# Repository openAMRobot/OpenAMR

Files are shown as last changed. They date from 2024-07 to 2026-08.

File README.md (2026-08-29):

# OpenAMRobot

## Turn Domain Expertise into Robotic Skills by Demonstration

### The Programming Language of Robotics is Domain Expertise.

OpenAMRobot is an open-source Physical AI development platform that enables startups, researchers, universities, and domain experts to build, train, validate, and deploy robotic solutions without rebuilding the entire robotics stack.

We believe the future of robotics will not be built by robotics engineers alone.

It will be built by:

- Manufacturing experts
- Logistics specialists
- Healthcare professionals
- Researchers
- Entrepreneurs
- Innovators

People who understand problems and want to automate them.

OpenAMRobot provides the infrastructure that transforms domain expertise into robotic capabilities.

---

# ⚠️ This Repository Has Moved

OpenAMR has evolved into a modular, better organized project.

As part of the **OpenAMRobot v0.0.1** release, the original repository has been split into dedicated repositories for hardware, software, firmware, and documentation.

## 📢 What Happened?

Most of the content previously available in this repository has been:

- ➜ migrated to **openamr-platform-hw**
- ➜ partially migrated to **openamr-platform-fw**
- ➜ reorganized into a modular repository structure
- ➜ updated with improved documentation and architecture

The legacy repository is now kept mainly for historical reference.

---
## 📦 New Project Structure

### 🛠️ Hardware
https://github.com/openAMRobot/openamr-platform-hw

Complete mechanical design, CAD, manufacturing files, BOM, electrical documentation, chassis, wiring, and assembly documentation.

### 🤖 Software
https://github.com/openAMRobot/openamr-platform-sw

ROS 2 Jazzy, Nav2, Gazebo Harmonic, SLAM, autonomous navigation, auto-docking, UI, simulation, Docker, and robotics software.

### ⚙️ Firmware
https://github.com/openAMRobot/openamr-platform-fw

micro-ROS firmware, motor control, odometry, IMU integration, PID control, telemetry, safety framework, and embedded software.

---
## 🚀 Watch the Release

OpenAMRobot v0.0.1 Release (https://www.youtube.com/shorts/LCLWUHWGkIY)

▶️ **OpenAMRobot v0.0.1 — First Public Release**

---

## ❤️ Continue the Journey

OpenAMRobot is becoming an open ecosystem for embodied AI, autonomous mobile robots, and mobile manipulation.

If you're looking for the latest development, please start here:

👉 https://github.com/openAMRobot

⭐ Star the project if you'd like to support open robotics.

---

## Why OpenAMRobot?

Building a modern Physical AI system requires expertise across:

- Robotics
- AI
- Perception
- Teleoperation
- Data collection
- Simulation
- Training infrastructure
- Deployment

Most teams spend months assembling infrastructure before they can validate a single robotic application.

OpenAMRobot reduces this complexity by providing an integrated development platform for:

- Mobile manipulation
- Teleoperation
- Data collection
- Imitation learning
- Embodied AI research
- Human-in-the-loop training
- Robot skill development
- Real-world deployment

**The fastest path from business problem to robotic solution.**

---

## Robotics 3.0

### Software evolution

**Software 1.0**  
Write code

**Software 2.0**  
Train models

**Software 3.0**  
Describe outcomes

### Robotics evolution

**Robotics 1.0**  
Program robots

**Robotics 2.0**  
Train robots

**Robotics 3.0**  
Teach robots by demonstration

OpenAMRobot is building the platform for Robotics 3.0.

---

## How it works

Domain Expert  
↓  
Demonstrates Task  
↓  
OpenAMRobot Collects Data  
↓  
AI Learns Skill  
↓  
Robot Executes Task

OpenAMRobot connects hardware, software, AI, and deployment into a single workflow.

---

## What OpenAMRobot provides

### Reference hardware

- Autonomous mobile robot platform
- Dual-arm mobile manipulation
- Adjustable lift systems
- Modular sensor architecture
- Open hardware designs

### Software infrastructure

- ROS 2 ecosystem
- Navigation and autodocking
- Teleoperation interfaces
- Simulation environments
- Embedded firmware

### Physical AI infrastructure

- Demonstration data collection
- ROS bag recording
- Dataset generation
- Imitation learning pipelines
- Foundation model integration
- Policy training workflows
- Deployment infrastructure

---

## Who is OpenAMRobot for?

### Today

- Robotics startups
- Universities
- Research laboratories
- Corporate innovation teams
- Venture builders

### Tomorrow

- Manufacturing
- Logistics
- Healthcare
- Agriculture
- Service robotics

Our users build robots.

Their users deploy robots.

---

## Why OpenAMRobot matters

Physical AI is creating a new generation of robots that learn from demonstration, adapt to new tasks, and solve real-world problems.

Yet building a trainable robot still requires expertise across hardware, software, AI, teleoperation, data collection, training pipelines, simulation, deployment, and hardware integration.

OpenAMRobot reduces this complexity by providing an integrated platform that enables anyone with domain expertise to create robotic solutions.

The real value is not the robot itself.

The real value is how efficiently a robotic system can solve a business problem.

---

## Our vision

The next generation of creators will not just build software.

They will build robots.

OpenAMRobot enables anyone with domain expertise to create robotic solutions without becoming a robotics engineer.

**The Programming Language of Robotics is Domain Expertise.**

---

## 💜 Support OpenAMRobot

Support open-source robotics, ROS 2 development, AI robotics education, and dual-arm mobile robot research.

### ⚡ Back the build — one-time, no strings

| Tier | What it says about you | Link |
|---|---|---|
| ⚡ **First Mover - €5** | You got here first, and you didn't overthink it. Your name goes on the backers wall - permanently - as one of the people who moved before it was obvious. Five euros, one good instinct. | <a href="https://buy.stripe.com/eVqcN5b99eeAaSd7WPgUM06" target="_blank" rel="noopener noreferrer">💳&nbsp;Back&nbsp;it&nbsp;→</a> |
| 🎯 **Sharpshooter - €25** | You spotted it early and called it. Name on the wall + a shareable "OpenAMRobot Backer" badge - proof you saw it coming while everyone else was still scrolling. | <a href="https://buy.stripe.com/4gMdR9ell1rO2lH90TgUM07" target="_blank" rel="noopener noreferrer">💳&nbsp;Back&nbsp;it&nbsp;→</a> |
| 🕶️ **Insider - €50** | You want in behind the curtain. Everything above + the backer-only build log and early files - every breakthrough, every faceplant, unfiltered. You see it before the internet does. | <a href="https://buy.stripe.com/eVq14nfpp4E0gcx2CvgUM08" target="_blank" rel="noopener noreferrer">💳&nbsp;Back&nbsp;it&nbsp;→</a> |
| 🔩 **Immortal - €100** | Your name goes on the actual robot. Physically. Forever. A machine will roll around carrying your name long after any of us remember why - and you'll have the photo to prove you were there. | <a href="https://buy.stripe.com/00w00jdhhb2o4tPfphgUM09" target="_blank" rel="noopener noreferrer">💳&nbsp;Back&nbsp;it&nbsp;→</a> |
| 🏆 **Founding Backer - €250** | Not a supporter - a co-author. Everything above + a personal thank-you in a build video. When this becomes something, you were one of the people who decided it would. | <a href="https://buy.stripe.com/28EeVdcdddawaSdeldgUM0a" target="_blank" rel="noopener noreferrer">💳&nbsp;Back&nbsp;it&nbsp;→</a> |

### 🔁 Monthly subscriptions — build it with us, every month

| Tier | What you get | Link |
|---|---|---|
| 😇 **Benefactor - €5/mo** | This month, officially not wasted. €5 to help build an open robot for everyone - cheaper than the coffee you'll forget you bought. Your name goes on the wall. History will remember you - well, me for sure. 🤖 | <a href="https://buy.stripe.com/9B6cN5dhh9Yk7G1cd5gUM05" target="_blank" rel="noopener noreferrer">💳&nbsp;Subscribe&nbsp;→</a> |
| ❤️ **Community - €19/mo** | You're in. Community access, project & roadmap updates, basic documentation, and community Q&A. (Private consultation not included.) | <a href="https://buy.stripe.com/6oUcN55OPc6s3pL4KDgUM00" target="_blank" rel="noopener noreferrer">💳&nbsp;Subscribe&nbsp;→</a> |
| 🔧 **Builder - €79/mo** | For the ones who actually build. Everything in Community + builder docs, monthly group Q&A, selected tutorials, early design updates, and discounts on digital packs. (Private consultation not included.) | <a href="https://buy.stripe.com/14A28r0uvdaw9O9eldgUM01" target="_blank" rel="noopener noreferrer">💳&nbsp;Subscribe&nbsp;→</a> |
| 🚀 **Pro Support - €299/mo** | Expert support for advanced builders, early founders, and small labs. Includes 1 private consulting call per month and up to 3 hours/month of technical guidance. | <a href="https://buy.stripe.com/dRm4gz4KLdaw6BX4KDgUM02" target="_blank" rel="noopener noreferrer">💳&nbsp;Subscribe&nbsp;→</a> |
| 🏢 **Startup Support - €750/mo** | For robotics startups and teams heading toward a prototype. Includes 2 private consulting calls per month, roadmap support, GitHub/documentation review, supplier review, and up to 6 hours/month. | <a href="https://buy.stripe.com/7sY8wPfpp8Ugf8t90TgUM03" target="_blank" rel="noopener noreferrer">💳&nbsp;Subscribe&nbsp;→</a> |
| 🔬 **Lab Support - €1,500/mo** | For universities, corporate labs, and training centers. Includes 4 private sessions per month, lab implementation support, architecture reviews, training-roadmap support, and up to 10 hours/month. | <a href="https://buy.stripe.com/eVq14ndhh2vSaSda4XgUM04" target="_blank" rel="noopener noreferrer">💳&nbsp;Subscribe&nbsp;→</a> |

**❤️ GitHub Sponsors:** <a href="https://github.com/sponsors/openAMRobot" target="_blank" rel="noopener noreferrer"> 🐙 &nbsp;github.com/sponsors/openAMRobot&nbsp;→</a>

*Every contribution — €5 or €1,500 — literally builds this robot. No billion-dollar lab required. **You're not donating. You're building it.** 🤖*

> [!IMPORTANT]
> ## OpenAMRobot Ecosystem
>
> OpenAMRobot is transitioning from a monolithic repository structure into a modular robotics ecosystem.
>
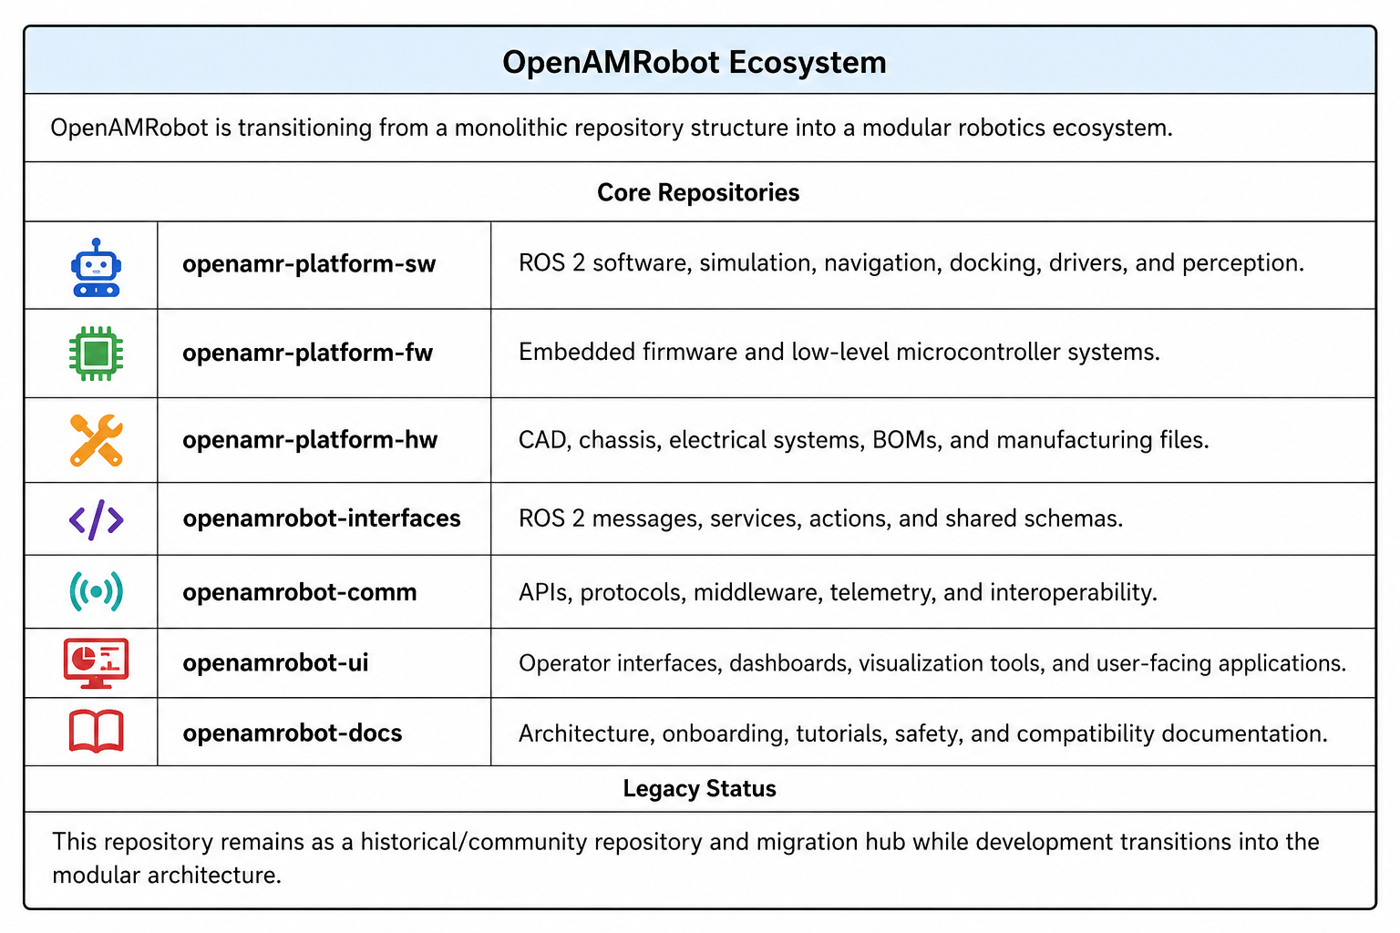
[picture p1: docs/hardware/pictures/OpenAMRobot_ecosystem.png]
OpenAMRobot Ecosystem
> 
>
> ### Core Repositories
>
> | Repository | Purpose |
> |---|---|
> | `openamr-platform-sw` | ROS 2 software, simulation, navigation, docking, drivers, perception, and robot bringup |
> | `openamr-platform-fw` | Embedded firmware, low-level microcontroller systems, motor interfaces, and hardware communication |
> | `openamr-platform-hw` | CAD, chassis, electrical systems, BOMs, manufacturing files, and mechatronics |
> | `openamrobot-interfaces` | ROS 2 messages, services, actions, shared schemas, and interface contracts |
> | `openamrobot-comm` | APIs, middleware, telemetry, transport protocols, interoperability, and fleet communication |
> | `openamrobot-ui` | Operator interfaces, dashboards, visualization tools, and user-facing applications |
> | `openamrobot-docs` | Architecture, onboarding, tutorials, safety, compatibility matrices, and contributor documentation |
>
> ### Future Expansion
>
> Planned future ecosystem areas include:
>
> - humanoid and dual-arm robotics
> - fleet management
> - cloud robotics
> - remote operation
> - AI-assisted autonomy
> - industrial integrations
> - educational platforms
>
> ### Legacy Status
>
> This repository remains as a historical/community repository and migration hub while development transitions into the modular architecture.

## Introduction

SMEs across multiple industries can significantly enhance their operations through the adoption of Collaborative Dual-Arm Autonomous Mobile Robots. 
In warehouses and distribution centers, such robots streamline goods movement and order fulfillment by combining autonomous navigation with dexterous dual-arm manipulation, enabling advanced G2P workflows and reducing manual handling. 
In manufacturing environments, they improve production efficiency by autonomously transporting materials between workstations and performing basic assembly or handling tasks. 
For last-mile logistics, including courier, express, parcel (CEP), and grocery delivery, dual-arm AMRs further boost operational efficiency by automating repetitive loading, sorting, and delivery operations.

Our project empowers you to build your own AMR using open-source designs and accessible manufacturing methods. This guide provides detailed drawings, 3D models, Bill of Materials (BOM), hardware architecture, navigation software, and user interface packages. Utilize straightforward manufacturing technologies to learn and integrate advanced automation seamlessly into your business operations.

## Key features

- **Navigation**: LIDAR/SLAM
- **Drive type**: Differential drive
- **Weight**: ~60 kg
- **Camera view**: 120 degrees
- **Speed**: 1500-2000 mm/s (unloaded), 1200-1500 mm/s (loaded)
- **Positioning accuracy**: ±20 mm
- **Dimensions**: 600x800 mm
- **Battery**: 24/48 V, 48-56 Ah, 8 hours life
- **Communication**: Wi-Fi (2.4/5 GHz)
- **Load capacity**: up to 150 kg
- **Operating temperature**: -10°C to +50°C
- **Charging**: Contact/wireless

## Design and manufacturing

Our design is optimized for manufacturability, requiring only basic technologies such as laser cutting, bending, turning (optional), and 3D printing (optional). Using mostly 2mm thick metal sheets, the design is robust yet simple to produce, allowing one person to build the robot in just one day if every part is ready.

Here is how the chassis design looks like:

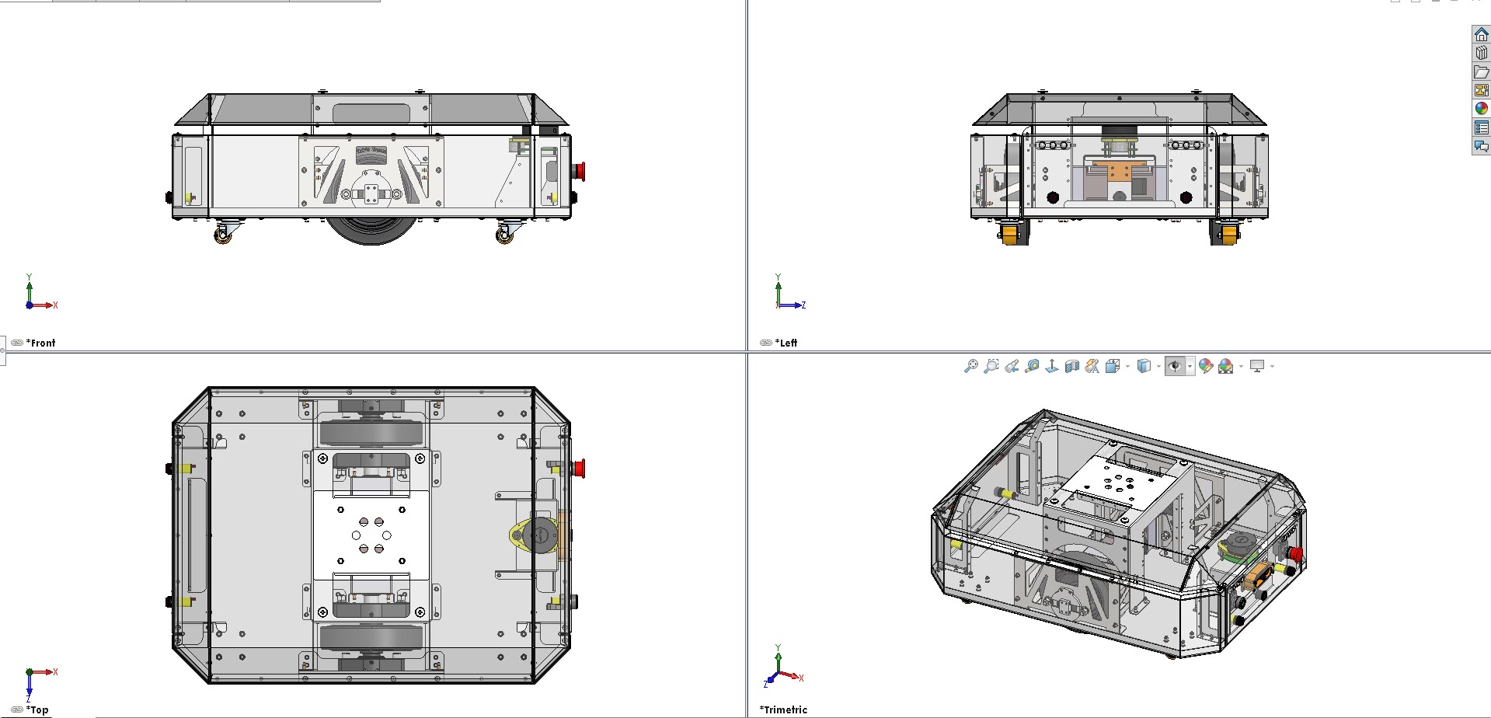
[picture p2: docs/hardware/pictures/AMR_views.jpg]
Mobile Robot General View


### Mechanical design and assembly

1. **Downloadable resources**:
    - Production drawings, 3D models, STEP, and DXF files
    - Specification sheet, including all parts and assemblies, sensors, and fasteners
2. **Fabrication process**:
    - Discuss the drawings with a contractor for cutting and bending metal.
    - Assemble the chassis following the provided sequence.
3. **Assembly steps**:
    - The chassis design and the recommended assembly sequence are illustrated in the provided images.
    - Detailed steps for assembling the drive wheels and other components are included.

### Hardware and software integration

1. **Electronics block diagram**:
    - Main single-board computer (SBC)
    - Safety sensors (US, IR, bumper), RPI camera, and LiDAR
    - Controller Teensy board and firmware
    - BLDC motors, drivers, and encoders
    - Batteries, BMS, and wireless charger
    - On/Off switch and Emergency button

2. **Main components**:
    - **Raspberry Pi 5**: For main computing tasks.
    - **LIDAR**: For mapping and navigation.
    - **Sensors**: For obstacle detection and safety.
    - **BLDC motors and drivers**: For movement control.
    - **Battery system**: For power supply.
    - **Wireless charging**: For autonomous charging.

3. **Software setup**:
    - **Linorobot**: Open-source software package for navigation and control.
    - **UI**: Built with Flask and Java for user interaction.
   
To get all files you should do the next commands:

        git clone https://github.com/openAMRobot/OpenAMR.git
  
        cd openAMR

        git submodule update --init --recursive

The **whole tutorial** about software installation is sectioned into different topics. Click [here](https://github.com/openAMRobot/OpenAMR/wiki/Getting-started) here to get started.
      
Here’s how the hardware architecture of the robot looks like:

Mobile Robot General View

### Practical applications and future enhancements

This versatile design can be adapted to create different types of robots for various logistics tasks. It can also be modified to carry tools or a roller cage, increasing its usefulness in various scenarios. Examples of practical applications include:

- Automating goods movement in warehouses
- Enhancing production workflows in manufacturing plants
- Improving operational efficiency in small farms and greenhouses

## Conclusion

This project provides a low-cost DIY autonomous mobile robot suitable for industrial automation or warehouse logistics. By open-sourcing our technology, we offer SMEs an opportunity to leverage advanced robotics without the high costs associated with research and development.

For any questions, please refer to the documentation or the open-source project Linorobot. Basic knowledge of electronics, software, and mechanics is required.

## Community management and moderation

Effective community management and moderation are essential to maintain a healthy and productive environment for collaboration. Our project welcomes contributions and feedback from the community to improve and evolve.

## Community profiles for public repositories

We are working on rules and suggestions to manage contributions and interactions within our repository. They include features like issue templates, pull request templates, and guidelines for contributors and will be published soon.

### A project's community profile

You can access the community profile of this repository by clicking on the "Community" tab on the repository's main page. This section provides all the necessary information and resources for contributors.

### A code of conduct 

We are preparing standards for behavior within the community. Information about Code of Conduct will be added soon to a `CODE_OF_CONDUCT.md` file in the root directory. Where we will outline the expected behavior and the process for reporting violations.

### Guidelines for repository contributors

We are working on information about the workflow, coding standards, and submission process to help contributors understand the best practices and expectations. This information will be outlined in a `CONTRIBUTING.md` file.

### License

This project is licensed under the MIT License. For more info please check `LICENSE` [LICENSE](https://github.com/openAMRobot/OpenAMR/blob/main/LICENSE) file in the root directory.

## Ownership, licensing, and contributions

OpenAMRobot is a project initiated, operated, and controlled by **Botshare LTD** (Cyprus Company ID HE479056). Botshare LTD owns the transferable economic rights in original OpenAMRobot material created by or validly assigned to it. Third-party material remains subject to its respective ownership, licences, and notices.

Original OpenAMRobot software and firmware are licensed under MIT, documentation under CC BY 4.0, and hardware design source under CERN-OHL-P-2.0, as mapped in [`LICENSING.md`](LICENSING.md). Public distribution grants the permissions stated in the applicable licence; it does not transfer ownership of underlying copyright, trademarks, patents, or other intellectual property.

Accepted external contributions require DCO sign-off and an applicable Individual or Corporate Contributor Agreement governing assignment of transferable economic rights to Botshare LTD. Contributor attribution and legally non-waivable authorship or moral rights remain recognized.

See the organization [IP Policy](https://github.com/openAMRobot/.github/blob/main/IP_POLICY.md), [Contribution Guide](https://github.com/openAMRobot/.github/blob/main/CONTRIBUTING.md), and [Contributor Agreement Process](https://github.com/openAMRobot/.github/blob/main/CLA.md).

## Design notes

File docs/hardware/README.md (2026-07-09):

## Project Overview

This folder contains detailed resources on the chassis, mechanics, assembly, and components of our project. The project currently utilizes electronics from the Linorobot project, which are sufficient for our needs. However, we have upgraded the controller and motor to more powerful, industrial-grade options.

### Folder Structure
- **BOM**: A comprehensive Bill of Materials, listing all components used in the project.
- **CAD_files**: 3D models and design files for the chassis and other mechanical parts.
- **datasheets**: Technical datasheets for the components, providing specifications and detailed information.
- **schematics**: Electrical schematics outlining the circuitry and connections (refer to Linorobot HW).

### For guidance on assembling the wheel, please refer to the video demonstrating the correct sequence:
[Wheel Assembly Video](https://youtu.be/FlsYwoiEAsk?feature=shared).

### For guidance on connecting the ZD BLDC motor and ZD driver, please refer to the picture below:

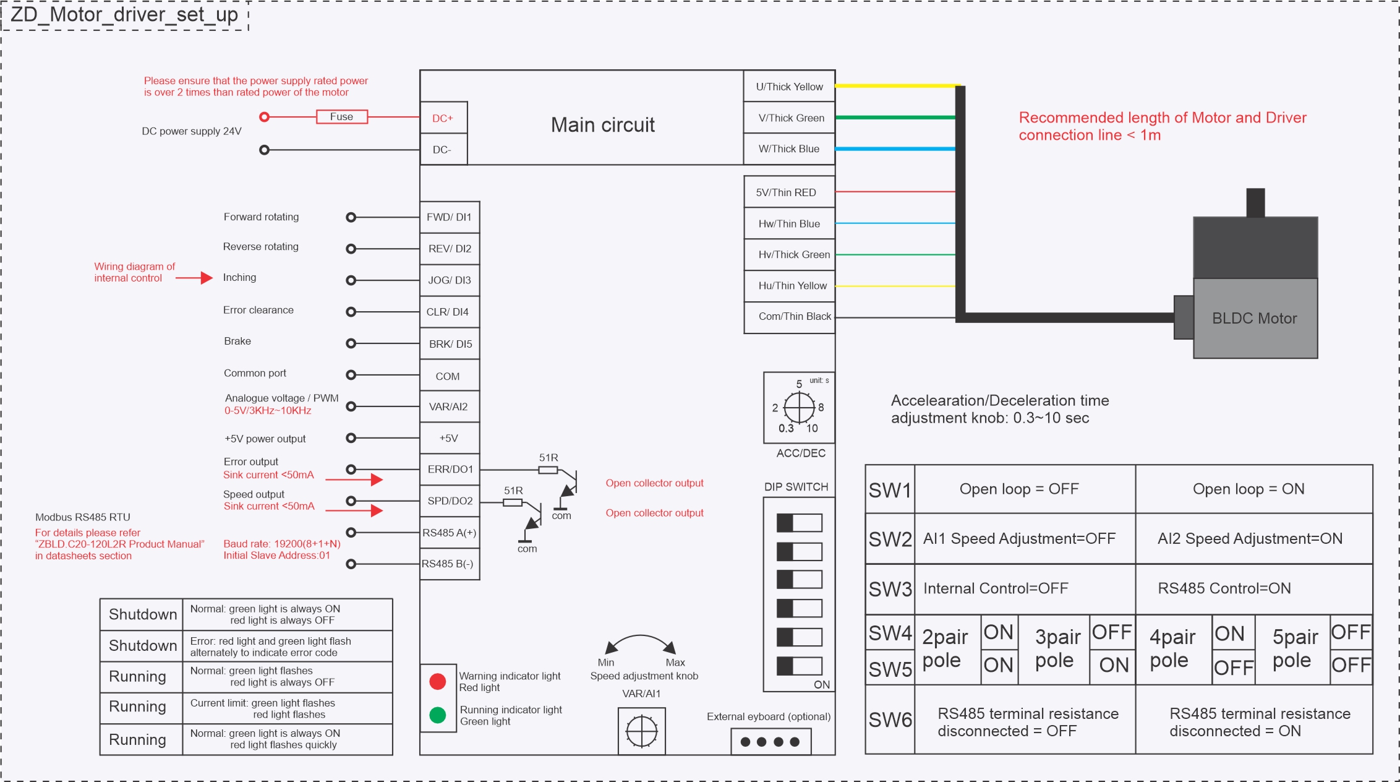
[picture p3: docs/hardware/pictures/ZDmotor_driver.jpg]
ZD BLDC motor and driver wiring diagram


## Support OpenAMRobot

Support open-source robotics, ROS2 development, AI robotics education, Dual-arm mobile robot research.

## 💜 Support OpenAMRobot

Support open-source robotics, ROS 2 development, AI robotics education, and dual-arm mobile robot research.

### ⚡ Back the build — one-time, no strings

| Tier | What it says about you | Link |
|---|---|---|
| ⚡ **First Mover - €5** | You got here first, and you didn't overthink it. Your name goes on the backers wall - permanently - as one of the people who moved before it was obvious. Five euros, one good instinct. | <a href="https://buy.stripe.com/eVqcN5b99eeAaSd7WPgUM06" target="_blank" rel="noopener noreferrer">💳&nbsp;Back&nbsp;it&nbsp;→</a> |
| 🎯 **Sharpshooter - €25** | You spotted it early and called it. Name on the wall + a shareable "OpenAMRobot Backer" badge - proof you saw it coming while everyone else was still scrolling. | <a href="https://buy.stripe.com/4gMdR9ell1rO2lH90TgUM07" target="_blank" rel="noopener noreferrer">💳&nbsp;Back&nbsp;it&nbsp;→</a> |
| 🕶️ **Insider - €50** | You want in behind the curtain. Everything above + the backer-only build log and early files - every breakthrough, every faceplant, unfiltered. You see it before the internet does. | <a href="https://buy.stripe.com/eVq14nfpp4E0gcx2CvgUM08" target="_blank" rel="noopener noreferrer">💳&nbsp;Back&nbsp;it&nbsp;→</a> |
| 🔩 **Immortal - €100** | Your name goes on the actual robot. Physically. Forever. A machine will roll around carrying your name long after any of us remember why - and you'll have the photo to prove you were there. | <a href="https://buy.stripe.com/00w00jdhhb2o4tPfphgUM09" target="_blank" rel="noopener noreferrer">💳&nbsp;Back&nbsp;it&nbsp;→</a> |
| 🏆 **Founding Backer - €250** | Not a supporter - a co-author. Everything above + a personal thank-you in a build video. When this becomes something, you were one of the people who decided it would. | <a href="https://buy.stripe.com/28EeVdcdddawaSdeldgUM0a" target="_blank" rel="noopener noreferrer">💳&nbsp;Back&nbsp;it&nbsp;→</a> |

### 🔁 Monthly subscriptions — build it with us, every month

| Tier | What you get | Link |
|---|---|---|
| 😇 **Benefactor - €5/mo** | This month, officially not wasted. €5 to help build an open robot for everyone - cheaper than the coffee you'll forget you bought. Your name goes on the wall. History will remember you - well, me for sure. 🤖 | <a href="https://buy.stripe.com/9B6cN5dhh9Yk7G1cd5gUM05" target="_blank" rel="noopener noreferrer">💳&nbsp;Subscribe&nbsp;→</a> |
| ❤️ **Community - €19/mo** | You're in. Community access, project & roadmap updates, basic documentation, and community Q&A. (Private consultation not included.) | <a href="https://buy.stripe.com/6oUcN55OPc6s3pL4KDgUM00" target="_blank" rel="noopener noreferrer">💳&nbsp;Subscribe&nbsp;→</a> |
| 🔧 **Builder - €79/mo** | For the ones who actually build. Everything in Community + builder docs, monthly group Q&A, selected tutorials, early design updates, and discounts on digital packs. (Private consultation not included.) | <a href="https://buy.stripe.com/14A28r0uvdaw9O9eldgUM01" target="_blank" rel="noopener noreferrer">💳&nbsp;Subscribe&nbsp;→</a> |
| 🚀 **Pro Support - €299/mo** | Expert support for advanced builders, early founders, and small labs. Includes 1 private consulting call per month and up to 3 hours/month of technical guidance. | <a href="https://buy.stripe.com/dRm4gz4KLdaw6BX4KDgUM02" target="_blank" rel="noopener noreferrer">💳&nbsp;Subscribe&nbsp;→</a> |
| 🏢 **Startup Support - €750/mo** | For robotics startups and teams heading toward a prototype. Includes 2 private consulting calls per month, roadmap support, GitHub/documentation review, supplier review, and up to 6 hours/month. | <a href="https://buy.stripe.com/7sY8wPfpp8Ugf8t90TgUM03" target="_blank" rel="noopener noreferrer">💳&nbsp;Subscribe&nbsp;→</a> |
| 🔬 **Lab Support - €1,500/mo** | For universities, corporate labs, and training centers. Includes 4 private sessions per month, lab implementation support, architecture reviews, training-roadmap support, and up to 10 hours/month. | <a href="https://buy.stripe.com/eVq14ndhh2vSaSda4XgUM04" target="_blank" rel="noopener noreferrer">💳&nbsp;Subscribe&nbsp;→</a> |

**❤️ GitHub Sponsors:** <a href="https://github.com/sponsors/openAMRobot" target="_blank" rel="noopener noreferrer"> 🐙 &nbsp;github.com/sponsors/openAMRobot&nbsp;→</a>

*Every contribution — €5 or €1,500 — literally builds this robot. No billion-dollar lab required. **You're not donating. You're building it.** 🤖*

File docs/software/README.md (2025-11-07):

### Project overview

This project provides a comprehensive solution for controlling a robot through a user-friendly web interface. It leverages the Robot Operating System (ROS) for robust communication and utilizes a web-based UI for intuitive interaction.

**Key components:**

*   **ROS package (ROS folder):**
    
    *   This folder contains the ROS package that acts as the brains of the user interface control system.
        
    *   It utilizes ROS nodes for communication, message definitions for data exchange, and services for specific functionalities.
        
    *   These components work together to send commands to the robot and receive sensor data for feedback.
        
*   **Web-based UI (UI folder):**
    
    *   This folder holds the source code for the web interface you'll interact with to control the robot.
        
    *   It includes HTML, CSS, and JavaScript code to define the layout, styling, and interactive behavior of the user interface.
        
*   **Firmware (firmware folder) (in development):**
    
    *   This folder contains the firmware code specifically designed for the different boards (like teensy or arduino) that controls the robot's hardware.
        
    *   It's the embedded software that translates commands received from the ROS package into actions for the robot's motors, sensors, and other components.
 




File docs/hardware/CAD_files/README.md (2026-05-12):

# CAD folder documentation

## Overview

This repository contains a variety of CAD drawings and 3D models in multiple formats. The files are organized into the following folders:

## Folder descriptions

### `STEP_full_assembly`

This folder includes STEP file MMP.00.00.00.000_full_assembly.STEP that represent the complete design or construction tree.

- **STEP files:** these files are compatible with various CAD programs, including SolidWorks, Catia, and AutoCAD. They adhere to the STEP (Standard for the Exchange of Product Data) format, which uses ASCII text to describe three-dimensional objects and models according to the ISO 10303 specification.

- **Usage:** use these files to restore and view full designs or construction assemblies in your preferred CAD software.

### `SW17_full_project`

This folder contains a complete project package, including all components, fasteners, printed circuit boards, and other parts, exemplified through a disinfection robot project.

**💡MMP - stands for Multipurpose Mobile Platform**

- **File compatibility:** these files are designed for SolidWorks version 2017 or newer.

- **Contents:** this comprehensive package includes all necessary components and models, providing a full representation of the project.

- **Folder Naming:** the main file is named `MMP.00.00.00.000_Multipurpose_mobile_platform`. After extracting all the files from MMP.00.00.00.000_Multipurpose_mobile_platform.zip into a single folder named `MMP.00.00.00.000_Multipurpose_mobile_platform`, locate the file with all zeros in the name, `MMP.00.00.00.000`, to open the full project.

### `Production_files`

This folder provides production-ready files in various formats that can be used to order parts without requiring specialized software.

- **File formats:** PDF, DXF, SLDDRW, and SLDPRT.

- **Usage:** these files contain detailed drawings and specifications sufficient for ordering parts directly from production facilities.

## File handling instructions

## Accessing and using projects

- **Full projects:** for example, in the `SW17_full_project` folder, use the file named `MMP.00.00.00.000` to open the full project in SolidWorks. 

- **Editing and improvements:** after opening the project, you can rename assemblies, edit, or improve the models. We encourage you to suggest improvements or report issues to the project.

## ⚠️Important notice for the sheet metal parts

Sheet metal parts are subject to production variations. The current designs are based on the following coefficients and radii:

- **Coefficient (K):** 0.47
- **Sheet metal specifications:**
  - **0.8 mm Sheet:** Radius (R) = 1.2
  - **1.2 mm Sheet:** Radius (R) = 1.5
  - **2.0 mm Sheet:** Radius (R) = 2.4

### Post-production

- Parts may be painted after bending.
- Riveting nuts can be installed before painting if the threaded part is protected from the coating.
- Screws installed without lock washers should be secured with a thread lock (e.g., Loxeal 55-03).

### 📜Bill of Materials (BOM) and list of assemblies, drawings, original parts 
Comprehensive list of all assemblies and their corresponding files in the [BOM repository](https://github.com/openAMRobot/OpenAMR/tree/main/docs/hardware/BOM). It also includes details on sheet metal parts, fasteners, technological operations, and origin components.

**Note:** All components are highly interconnected and their functionality is dependent on one another.

## Contributing

If you wish to contribute to the project:

Support open-source robotics, ROS2 development, AI robotics education, Dual-arm mobile robot research.

### Monthly subscriptions

| Tier | Price | Link |
|---|---:|---|
| Community | €19/month | <a href="https://buy.stripe.com/6oUcN55OPc6s3pL4KDgUM00" target="_blank">Subscribe</a> |
| Builder | €79/month | <a href="https://buy.stripe.com/14A28r0uvdaw9O9eldgUM01" target="_blank">Subscribe</a> |
| Pro Support | €299/month | <a href="https://buy.stripe.com/dRm4gz4KLdaw6BX4KDgUM02" target="_blank">Subscribe</a> |
| Startup Support | €750/month | <a href="https://buy.stripe.com/7sY8wPfpp8Ugf8t90TgUM03" target="_blank">Subscribe</a> |
| Lab Support | €1,500/month | <a href="https://buy.stripe.com/eVq14ndhh2vSaSda4XgUM04" target="_blank">Subscribe</a> |

GitHub Sponsors: https://github.com/sponsors/openAMRobot

Every contribution, big or small, helps us grow. Thank you for your support!

- **Issue reporting:** use the [ISSUE_TEMPLATE.md](https://github.com/openAMRobot/.github/blob/main/ISSUE_TEMPLATE.md) for reporting issues.
- **Submitting pull requests:** use the [PULL_REQUEST_TEMPLATE.md](https://github.com/openAMRobot/.github/blob/main/PULL_REQUEST_TEMPLATE.md) for submitting improvements or changes.
- **Contributing guidelines:** please read the [CONTRIBUTING.md](https://github.com/openAMRobot/OpenAMR/blob/main/CONTRIBUTING.md) for detailed contribution guidelines.

For further assistance, please refer to the repository’s main documentation or contact the repository maintainers.

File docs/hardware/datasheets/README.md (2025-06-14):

# Mechanical, electrical and control calculations

## 1. Mechanical, electrical, and control calculations for wheel-motor-driver mechatronic system {#mechanical-electrical-and-control-calculations-for-wheel-motor-driver-mechatronic-system}

### 1.1 Motor and gearbox overview {#motor-and-gearbox-overview}

| **Parameter**  | **Value** |
|---|---|
| Motor Model | ZDBLD60-24GN-30S |
| Rated Power | 60 W |
| Rated Voltage  | 24 V DC |
| Rated Speed | 3000 RPM (no load) |
| Gearbox Model  | 4GN 25K |
| Gear Ratio | 1 : 25 |
| Wheel Diameter | 200 mm |
| Drive Type | Differential drive |
| Driver | ZBLD C20 120L2R |

### 1.2 Definitions of main terms {#definitions-of-main-terms}

| **Term** | **Definition** |
|---|---|
| RPM | Revolutions per minute - the number of full rotations completed in one minute |
| Torque (T) | Rotational force output, measured in Newton-meters (Nm) |
| Gear Ratio (GR)  | The ratio of motor speed to output speed, or torque multiplication factor |
| Wheel Radius (r) | Half of the wheel diameter, in meters |
| Linear Speed (v) | Speed of vehicle movement on the ground surface (m/s) |
| Current (I) | Electric current drawn by the motor, measured in Amperes (A) |
| Power (P) | The rate of energy use or work done, measured in Watts (W) |

## 2. Motor output calculations {#motor-output-calculations}

### 2.1 Output RPM after gearbox {#output-rpm-after-gearbox}

**Formula:**

RPM_output = Motor_RPM / Gear_Ratio

**Substituting:**

RPM_output = 3000 / 25

**Result:**

RPM_output = 120 RPM

### 2.2 Torque at wheel after gearbox {#torque-at-wheel-after-gearbox}

**Formula:**

T_output = (P × t_sec) / (2 × π × Motor_RPM) × Gear_Ratio

Where:

- P is motor power (W)

- t_sec is the time conversion constant (60 seconds per minute)

- Motor_RPM is motor shaft speed before gearbox

- Gear_Ratio increases torque after gearbox

**Substituting:**

T_output = (60 × 60) / (2 × 3.1416 × 3000) × 25

**Result:**

T_output ≈ 4.77 Nm

### 2.3 Wheel peripheral speed {#wheel-peripheral-speed}

First, calculate wheel radius:

**Formula:**

r = Wheel_Diameter / 2

**Substituting:**

r = 0.2 m / 2

r = 0.1 m

Peripheral (linear) speed at output RPM:

**Formula:**

v = (2 × π × r × RPM_output) / t_sec

**Substituting:**

v = (2 × 3.1416 × 0.1 × 120) / 60

**Result:**

v ≈ 1.26 m/s

## 3. Electrical calculations {#electrical-calculations}

### 3.1 Rated current estimation {#rated-current-estimation}

Formula:

I = P / V

**Substituting:**

I = 60 / 24

**Result:**

I = 2.5 A

**Note:  
**Actual working current will be higher under load due to system
inefficiencies (e.g., friction, heat losses).

### 3.2 Current at peak load {#current-at-peak-load}

Startup or full-load current is typically 2× to 3× rated current:

**Estimated peak:**

Peak_Current ≈ 5 A to 7.5 A

## 4. Control system summary {#control-system-summary}

| **Component** | **Function** |
|---|---|
| Teensy microcontroller | Low-level motor control and sensor feedback |
| RS485 bus | Communication with ESC driver (control + feedback) |
| Raspberry Pi 5 (ROS2)  | High-level control (navigation, SLAM, teleoperation) |
| Motor driver modes | RS485-based, optional PWM fallback |

## 5. Additional control-related calculations {#additional-control-related-calculations}

### 5.1 Encoder feedback via Hall sensors {#encoder-feedback-via-hall-sensors}

- Built-in Hall sensors inside the BLDC motor.

- Motor controller reads the Hall sensors and provides RPM data via
  > RS485 to Teensy.

**Odometry calculation basics:**

Formula for distance per wheel revolution:

Distance_per_revolution = 2 × π × r

Substituting:

Distance_per_revolution = 2 × 3.1416 × 0.1

Distance_per_revolution = 0.628 m

If the controller updates 100 times per second, each sample provides
partial movement estimation for odometry accumulation.

## 6. Summary table of key results {#summary-table-of-key-results}

| **Parameter** | **Value** |
|---|---|
| Output wheel speed | ≈ 120 RPM |
| Output torque at wheel | ≈ 4.77 Nm |
| Maximum ground speed | ≈ 1.26 m/s |
| Rated current | 2.5 A |
| Peak load current | 5 A to 7.5 A |

## 7. Important notes {#important-notes}

- Real-world values may vary due to surface friction, payload, battery
  > state, etc.

- Proper safety margins (fuses, BMS limits) must be applied based on
  > peak current estimates.

- Odometry may use RPM data rather than physical encoders.

- Battery capacity must accommodate peak currents during acceleration
  > and emergency maneuvers.

## 8. Why these calculations matter {#why-these-calculations-matter}

| **Area** | **Reason** |
|---|---|
| Mechanical | Ensures correct motor sizing, gearbox matching, wheel performance |
| Electrical | Ensures correct wiring, battery choice, BMS setup, safety |
| Control | Accurate feedback loop tuning, stable autonomous operation |
| Project success | Avoids overheating, overload, loss of control, and unsafe operation |

# Real world examples

## 1. Introduction {#introduction}

In robotics and mechatronics, calculations must be connected to
real-world operating conditions to ensure systems are:

- Safe

- Reliable

- Efficient

- Cost-effective

### 1.1 Delivery robot example {#delivery-robot-example}

A delivery robot must carry a **45 kg load** up a **10° slope**.  
Without correct motor torque sizing and battery estimation:

- It might **fail to climb**.

- It could **overload** the motors and electronics.

- It might **drain the battery too fast**.

Thus, precise force, torque, power, and control calculations are
essential before building.

### 1.2 Warehouse robot example {#warehouse-robot-example}

A robot operating on smooth surfaces (like tiles or polished concrete)
will:

- Require **lower starting torque** (less friction).

- Require **very accurate braking and steering** (to avoid sliding).

PID tuning and odometry corrections become critical.

### 1.3 Circle length calculation {#circle-length-calculation}

**Definition:** Circle circumference

**Circumference** is the total distance around the edge of a circle.

**Formula**:

C = 2 × π × r

Where:

- C = Circumference (meters, m)

- π ≈ 3.1416 (pi, a mathematical constant)

- r = Radius of the circle (meters)

**Example** (wheel radius 0.1 m):

C = 2 × 3.1416 × 0.1

C ≈ 0.628 m

**Meaning**:  
One complete wheel rotation moves the robot **62.8 cm forward**.

## 2. Torque and speed for real mass (45 kg) {#torque-and-speed-for-real-mass-45-kg}

### 2.1 Definition: Force (F) {#definition-force-f}

**Force** is an interaction that causes an object to change its motion
(accelerate).

**Formula**:

F = m × a

Where:

- F = Force (newtons, N)

- m = Mass (kilograms, kg)

- a = Acceleration (meters per second squared, m/s²)

**Calculation** (for 0.5 m/s² acceleration):

F = 45 × 0.5

F = 22.5 N

### 2.2 Definition: Torque (T) {#definition-torque-t}

**Torque** is the rotational equivalent of force. It measures how much a
force causes an object to rotate around an axis.

**Formula**:

T = F × r

Where:

- T = Torque (newton-meters, Nm)

- r = Lever arm (wheel radius in meters)

**Calculation**:

T = 22.5 × 0.1

T = 2.25 Nm

**Meaning**:  
Each wheel must apply at least **2.25 Nm** of torque to accelerate the
robot at 0.5 m/s².

## 3. Power consumption calculation {#power-consumption-calculation}

### 3.1 Definition: Power (P) {#definition-power-p}

**Power** is the rate of doing work, or transferring energy.

**Formula**:

P = F × v

Where:

- P = Power (watts, W)

- F = Force (newtons, N)

- v = Velocity (meters per second, m/s)

**Calculation** (target speed 1.26 m/s):

P = 22.5 × 1.26

P ≈ 28.35 W

**Meaning**:  
At full speed, the robot needs about **28.35 watts** to maintain its
motion against resistance.

## 4. Slopes (positive and negative) {#slopes-positive-and-negative}

### 4.1 Definition: Slope {#definition-slope}

A **slope** is an inclined surface. In physics, moving on a slope means
additional forces act along the direction of motion due to gravity.

### 4.2 Positive slope (climbing) {#positive-slope-climbing}

**Formula for slope force**:

F_slope = m × g × sin(θ)

Where:

- g = 9.81 m/s² (gravity acceleration)

- θ = Slope angle in degrees

**Example for 10° slope**:

F_slope = 45 × 9.81 × sin(10°) ≈ 45 × 9.81 × 0.1736 ≈ 76.6 N

**Meaning**:  
An additional **76.6 N** must be overcome by the motors when climbing a
10° incline.

### Additional force on slope, torque, and power calculation

#### 1. What does \"an additional 76.6 N must be overcome\" mean? {#what-does-an-additional-76.6-n-must-be-overcome-mean}

When a robot moves **on flat ground**, the motors must overcome:

- **Inertia** (mass resisting change of motion).

- **Rolling resistance** (small friction at wheels).

- **Small air resistance** (negligible at low robot speeds).

On flat ground, the **required force to accelerate** the robot is:

F_flat = m × a

Where:

- m = mass (kilograms, kg)

- a = acceleration (meters per second squared, m/s²)

Given:

- m = 45 kg

- a = 0.5 m/s²

Calculation:

F_flat = 45 × 0.5 = 22.5 N

Thus, **on a flat surface**, **22.5 N** is needed to start or accelerate
the robot.

When **climbing a slope** (an inclined surface):

- Gravity exerts an additional **downward force** along the slope.

- This additional force must be **overcome by the motors** to prevent
  > rolling backwards.

The **slope force** is:

F_slope = m × g × sin(θ)

Where:

- g = 9.81 m/s² (gravitational acceleration),

- θ = slope angle in degrees.

Given:

- θ = 10°

- sin(10°) ≈ 0.1736

Calculation:

F_slope = 45 × 9.81 × 0.1736

F_slope ≈ 76.6 N

#### 2. Total force needed when climbing {#total-force-needed-when-climbing}

The **total force** the robot motors must produce when climbing is the
**sum** of:

- The normal force to accelerate horizontally (F_flat),

- The additional force to overcome gravity (F_slope).

Thus:

F_total = F_flat + F_slope

Substituting:

F_total = 22.5 + 76.6

F_total ≈ 99.1 N

#### 3. Why \"an additional 76.6 N\"? {#why-an-additional-76.6-n}

**Meaning**:

- Motors already must produce **22.5 N** to accelerate the robot
  > horizontally.

- **When climbing**, they must generate an **extra 76.6 N** to resist
  > the gravitational pull downhill.

Thus, a total of **99.1 N** must be overcome to climb while
accelerating.

#### 4. Torque required for slope climbing {#torque-required-for-slope-climbing}

**Definition: Torque**

**Torque** is a measure of the rotational force applied around an axis
(for example, the wheel axle).

**Formula**:

T = F × r

Where:

- T = Torque (newton-meters, Nm)

- F = Force (newtons, N)

- r = Wheel radius (meters, m)

Given:

- F_total = 99.1 N

- r = 0.1 m

Calculation:

T = 99.1 × 0.1

T ≈ 9.91 Nm

**Differential drive: two motors**

In a **differential drive** system:

- Two wheels share the load.

- Each wheel must provide **half** the total torque.

Thus, **torque per wheel**:

T_per_wheel = T_total / 2

Substituting:

T_per_wheel = 9.91 / 2

T_per_wheel ≈ 4.955 Nm

#### 5. Power required for slope climbing {#power-required-for-slope-climbing}

**Definition: Power**

**Power** is the rate at which work is done or energy is transferred.

**Formula**:

P = F × v

Where:

- P = Power (watts, W)

- F = Force (newtons, N)

- v = Velocity (meters per second, m/s)

Assume target velocity:

- v = 1.26 m/s (as given earlier)

Calculation:

P = 99.1 × 1.26

P ≈ 124.9 W

Thus, total **mechanical power required** to climb at 1.26 m/s is
**about 125 W**.

If divided equally between two motors:

P_per_motor ≈ 62.45 W

#### 6. Summary table {#summary-table}

| **Parameter** | **Value** | **Explanation** |
|---|---|---|
| Force on flat ground | 22.5 N | Force to accelerate horizontally. |
| Additional force on 10° slope | 76.6 N | Extra gravitational force to overcome. |
| Total force to climb | 99.1 N | Combined force needed. |
| Total torque required | 9.91 Nm | Torque needed from both wheels combined. |
| Torque per wheel | 4.955 Nm  | Torque needed from each wheel. |
| Total power required | 124.9 W | Power needed to maintain speed uphill. |
| Power per motor | 62.45 W | Power per wheel motor. |

#### 7. Final explanation {#final-explanation}

- On flat ground, motors must provide **only inertia-based force**.

- On slopes, **gravity adds extra load**.

- Motors must be sized not only for flat motion but also for
  > **worst-case scenarios** like climbing.

- Correct calculation ensures the robot **can climb safely** without
  > overloading motors or batteries

### 4.3 Negative slope (descending) {#negative-slope-descending}

When descending:

- Gravity **accelerates** the robot downhill.

- Motors must provide **braking torque** to **control the descent**.

- PID controllers must be tuned to avoid **unstable behavior**.

## 5. PID controller definition {#pid-controller-definition}

### 5.1 What is a PID controller? {#what-is-a-pid-controller}

A **PID controller** is a control algorithm used in mechatronics to
automatically adjust motor output to reach and maintain a desired value
(e.g., speed, position).

**Components**:

| **Part** | **Description** |
|---|---|
| Proportional (P) | Corrects based on current error (fast response). |
| Integral (I) | Corrects based on accumulated error over time (eliminates steady-state error). |
| Derivative (D) | Predicts future errors (damps oscillations and overshoot). |

**Why use PID?**

- To control motor speed and position **smoothly and accurately**.

- To react dynamically to changes (slopes, friction).

## 6. Differential drive system total torque {#differential-drive-system-total-torque}

### 6.1 Definition: Differential drive {#definition-differential-drive}

A **differential drive** robot moves by varying the speed and direction
of two independently driven wheels.

- Moving straight: both wheels at the same speed.

- Turning: wheels at different speeds or opposite directions.

### 6.2 Calculating total torque {#calculating-total-torque}

Each wheel must provide torque individually.

**Formula**:

T_total = 2 × T_single_wheel

Example:

T_total = 2 × 2.25 = 4.5 Nm

**Meaning**:  
For straight acceleration, the **robot needs 4.5 Nm total** distributed
equally between the two motors.

## 7. Encoder and resolution calculation {#encoder-and-resolution-calculation}

### 7.1 Definition: Encoder {#definition-encoder}

An **encoder** is a sensor that generates a number of pulses or signals
for every rotation of a shaft, enabling precise measurement of rotation.

### 7.2 Effective encoder resolution {#effective-encoder-resolution}

If an encoder outputs **500 pulses per motor revolution**, and the
gearbox has **25:1 reduction**:

Wheel_PPR = 500 × 25 = 12,500 pulses per wheel revolution

**Distance per pulse**:

Distance_per_pulse = Circumference / Wheel_PPR

Distance_per_pulse = 0.628 / 12,500 ≈ 0.00005024 m ≈ 0.05 mm

**Meaning**:  
Each encoder pulse corresponds to **about 0.05 mm** of wheel movement.

## 8. PWM definition {#pwm-definition}

8.1 What is PWM?

**Pulse width modulation (PWM)** is a technique to control the amount of
power delivered to an electrical device by switching it ON and OFF
rapidly.

- **Duty cycle**: the proportion of time the signal is ON during one
  > cycle.

- **Higher duty cycle** = **more power** to the motor.

**Example**:

- 50% duty cycle → motor receives half the full voltage.

- 80% duty cycle → motor receives 80% of full voltage.

## 9. Real robot velocity vs estimated one, feedback, odometry {#real-robot-velocity-vs-estimated-one-feedback-odometry}

### 9.1 Definition: Odometry {#definition-odometry}

**Odometry** is the process of using data from sensors (like wheel
encoders) to estimate a robot's position and orientation over time.

### 9.2 Real world vs estimated {#real-world-vs-estimated}

- **Estimated position** comes from calculated wheel movement.

- **Real position** may differ due to:

  - Slippage

  - Uneven floor

  - Wheel deformation

  - Encoder errors

### 9.3 Feedback mechanisms {#feedback-mechanisms}

| **Sensor** | **Purpose** |
|---|---|
| Wheel encoder | Measure rotation and distance. |
| Hall sensor | Measure motor shaft speed. |
| Inertial Measurement Unit (IMU) | Measure acceleration and rotation. |
| Visual odometry | Use cameras to correct position estimates. |

## 10. Conclusion {#conclusion}

With these advanced calculations, definitions, and considerations:

- Mechanical design is validated for forces, torques, and slopes.

- Electrical system sizing (current, power) is validated.

- Control system design (PID, PWM, odometry) is fully prepared.

- Real-world operating conditions are considered for accuracy and
  > safety.

## Diagram 1: Forces on flat ground

Top view - Robot moving forward on flat ground    
    
         (Front of robot)    
                ↑    
                |    (Force F_flat = m × a)    
                |    
           +----+----+    
           |         |    ----->   Direction of motion    
           |  ROBOT  |    
           |         |    
           +----+----+    
                |    
                v    
          (Rear of robot)    

Forces:

\- F_flat: needed to accelerate mass.

\- Minor frictional forces oppose motion (small).

\- No gravity component along the ground.

**Key points**:

- Only acceleration force and rolling friction matter.

- Motors must produce enough torque to create F_flat.

## Diagram 2: Forces when climbing a slope

Side view - Robot climbing a slope

              (Gravity force m×g)    
                       ↓    
                    +----+    
                   /      \    
                  /  ROBOT \    
                 +----------+    
                θ (slope angle)    

Forces:

\- Gravity splits into two components:

\- Perpendicular to slope (presses robot against slope).

\- Parallel to slope (tries to pull robot downwards):

F_slope = m × g × sin(θ)

\- Motors must overcome:

\- F_flat (for acceleration)

\- F_slope (gravity component)

Resulting Force:

F_total = F_flat + F_slope

**Key Points**:

- Slopes introduce significant additional force requirements.

- Steeper slopes = larger sin(θ) = larger F_slope.

- Motors must deliver both torque for acceleration **and** additional
  > torque for gravity.

## Diagram 3: Torque generation at the wheel

Side view of one drive wheel    

        [Motor Shaft]---->[Gearbox]---->[Wheel]    
                                 |    
                                 v    
                                (r)    
                                 |    
                                [Ground]    

**Forces:**

\- Torque T = F × r

\- Force F is exerted by wheel against ground.

\- Radius r is the lever arm.

\- Ground applies reaction force to move robot forward.

**How it works:**

\- Motor produces torque T.

\- Torque T pushes the wheel rim.

\- Wheel transfers force to ground, robot moves.

*Bigger radius → More force needed.*

*Bigger force → More torque needed.*

**Key points**:

- The larger the wheel, the larger torque needed.

- Torque is rotational force; it directly defines a robot\'s ability to
  > start moving or climb slopes.

**Summary**

| **Diagram** | **Represents** | **Key Forces/Concepts** |
|---|---|---|
| Diagram 1 | Flat ground motion | Only F_flat needed to accelerate.  |
| Diagram 2 | Uphill motion | F_flat + F_slope must be overcome. |
| Diagram 3 | Wheel torque generation | T = F × r relationship explained.  |

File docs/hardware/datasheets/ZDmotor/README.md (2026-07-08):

Contact:
web: [https://zd-motor.com](https://www.zd-motor.com/)

Nunmulman Chai     
> Sales Engineer     
> NINGBO ZHONGDA LEADER INTELLIGENT TRANSMISSION CO.,LTD.     
> trade26@zd-motor.com    
> sales@zd-motor.com
> 
>86 13566315316
> No.185 1ST,NEW INDUSTRIAL ZONE,ZONGHAN STREET,CIXI ZHEJIANG, CHINA, 315300     

**T: 86 0574 63537171**    
**wechat：czy13566315316**

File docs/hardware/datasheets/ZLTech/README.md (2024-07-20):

ZLTech components.
Sz EXW preliminary price:
Wheel: ZLLG80ASM250-L V1.0 - 115USD/1pc
Driver: ZLAC8015D - 145USD/1pc

The total price: 115USD*2pc+145USD=375USD

Contact:
Finkle: finkle@zlingkj.com
Melady: melady@zlingkj.com

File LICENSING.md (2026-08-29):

# OpenAMRobot licensing standard

OpenAMRobot uses asset-appropriate permissive licences for original material owned by or validly assigned to **OpenAMRobot (Botshare LTD)**.

| Material | Licence |
|---|---|
| Software, firmware, scripts, configuration, APIs, tests, and code examples | [MIT](https://spdx.org/licenses/MIT.html) |
| Documentation, diagrams, tutorials, original images, and other authored content | [Creative Commons Attribution 4.0 International](https://spdx.org/licenses/CC-BY-4.0.html) |
| CAD, PCB and schematic source, mechanical/electrical design files, manufacturing source, and CAD-derived robot geometry | [CERN Open Hardware Licence Version 2 — Permissive](https://spdx.org/licenses/CERN-OHL-P-2.0.html) |

Copyright (c) 2021–2026 OpenAMRobot (Botshare LTD).

The root `LICENSE` identifies the predominant licence for this repository. Where a repository contains several asset types, the table above and any more specific file, directory, SPDX, package, or notice declaration determine the applicable licence.

## Third-party material

No OpenAMRobot licence relicenses third-party material. Third-party material remains governed by its original ownership, licence, patent, attribution, modification, and source-availability terms. Specific third-party terms control over this general policy and are recorded in source headers, dependency manifests, `NOTICE.md`, `THIRD_PARTY_NOTICES.md`, accompanying licence files, or the material itself.

## Ownership and branding

Public licensing grants the permissions in the applicable licence; it does not transfer ownership of the underlying intellectual property. OpenAMRobot, OpenAMR, associated logos, visual identity, and claims of official affiliation or certification are not licensed under MIT, CC BY 4.0, or CERN-OHL-P-2.0. See the organization [Trademark Policy](https://github.com/openAMRobot/.github/blob/main/TRADEMARK_POLICY.md).

## Earlier distributions

Licences validly granted for earlier copies remain effective for those copies. The current default branch states the policy for current and future distributions, subject to third-party rights and mandatory law.

Licensing and provenance questions: **info@botshare.ai**.

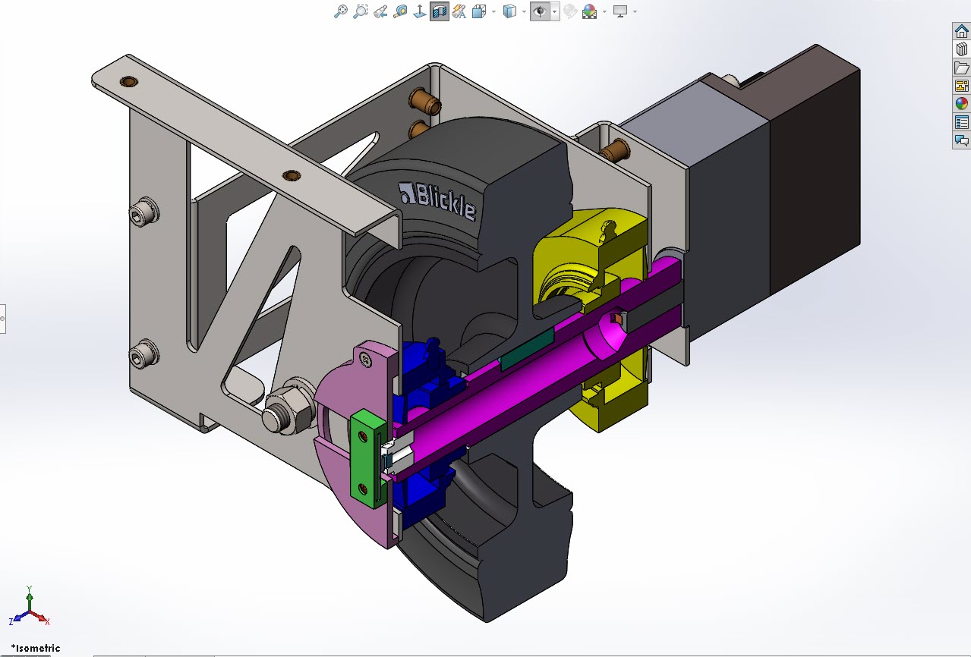
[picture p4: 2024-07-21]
docs/hardware/CAD_files/production_files/MMP_05.jpg

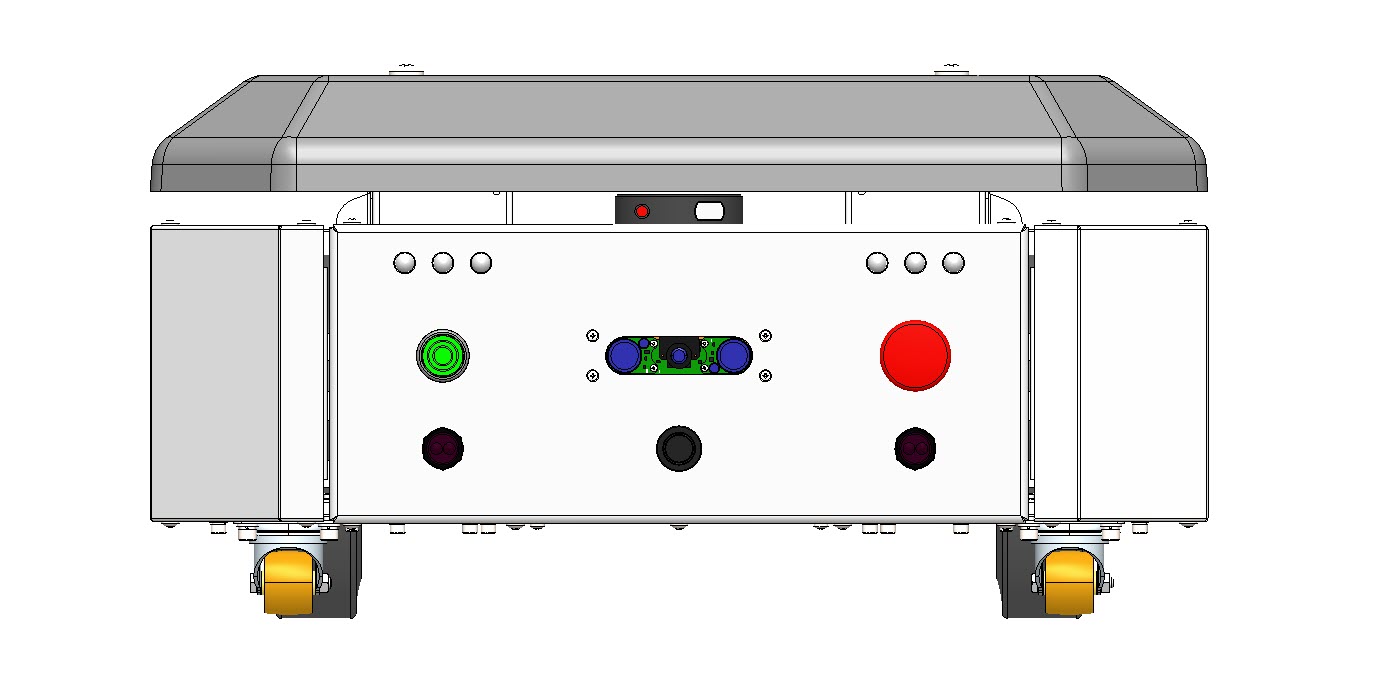
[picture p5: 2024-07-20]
docs/hardware/pictures/AMR_front_view.jpg

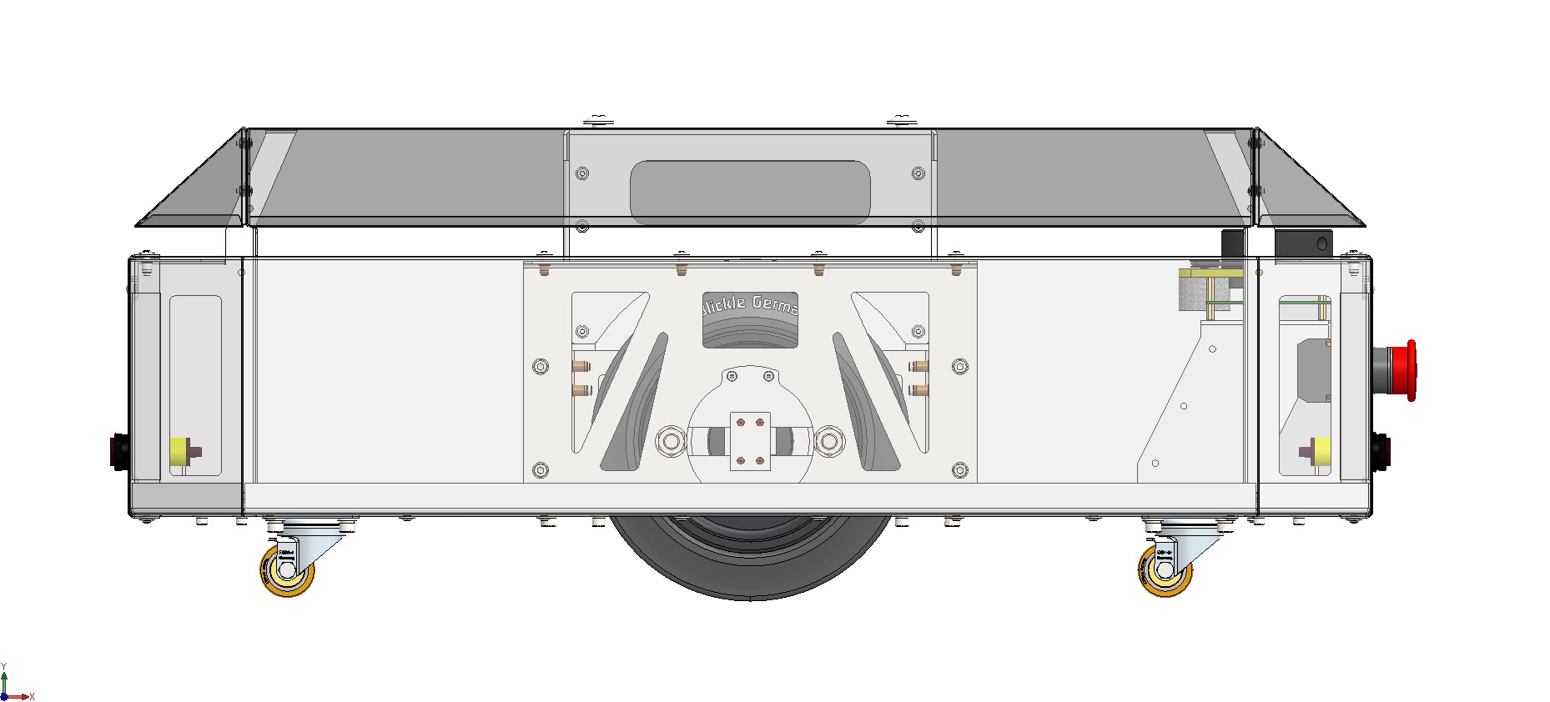
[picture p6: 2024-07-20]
docs/hardware/pictures/AMR_side_view.jpg

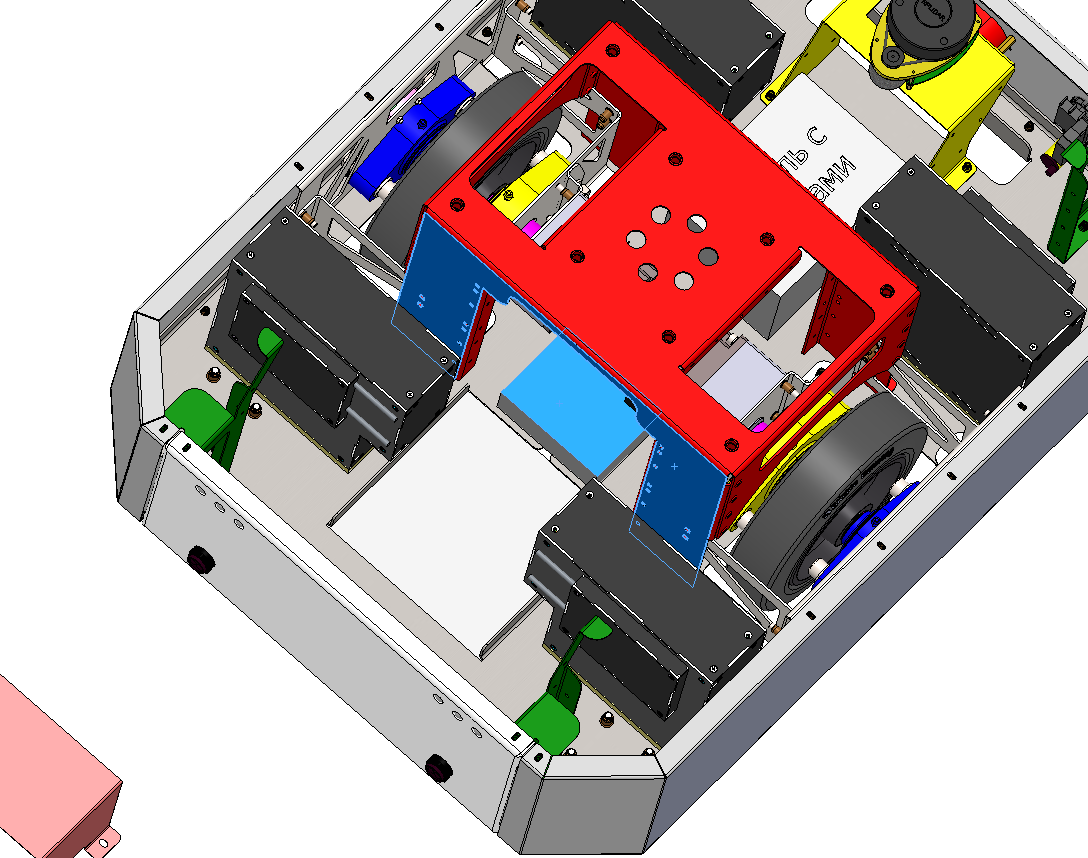
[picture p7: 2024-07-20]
docs/hardware/pictures/AMR_uncovered.png

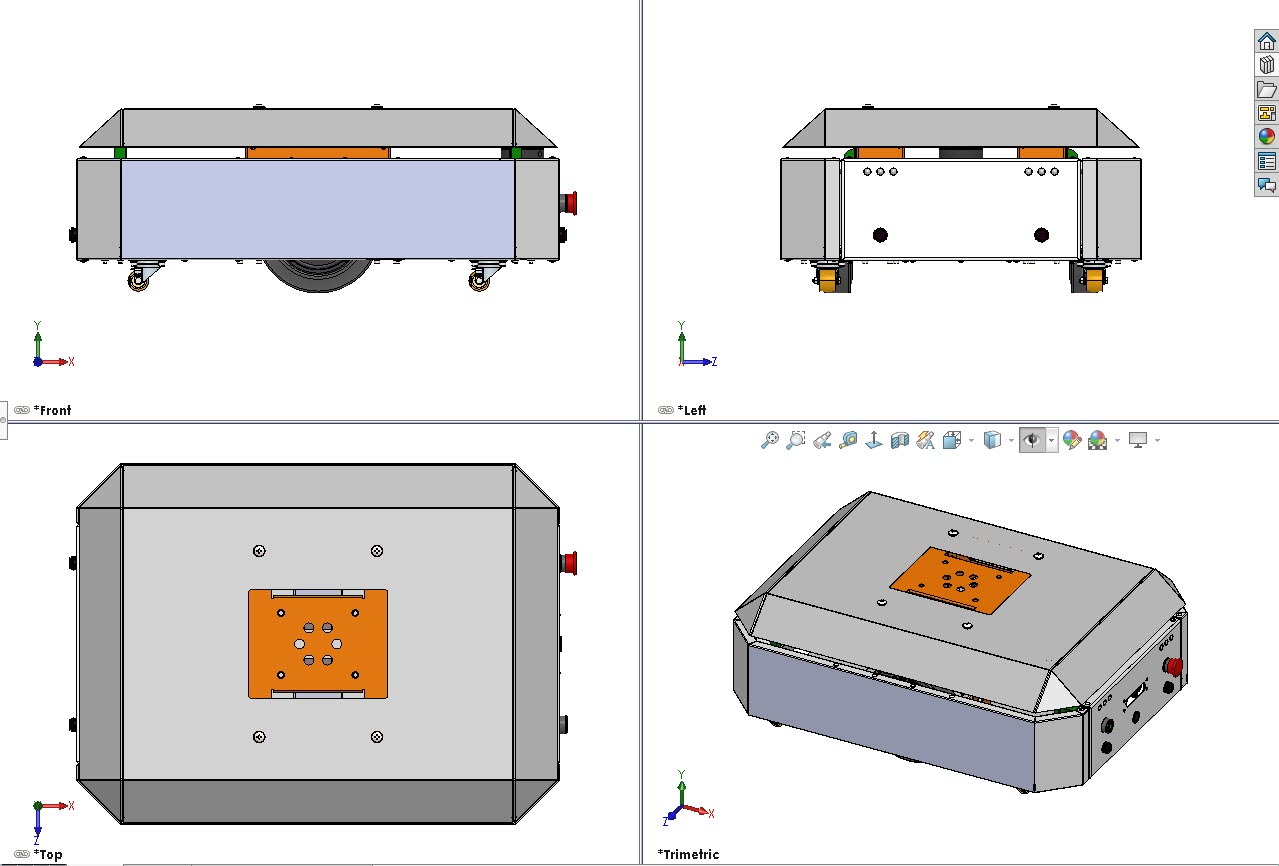
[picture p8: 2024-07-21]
docs/hardware/CAD_files/production_files/MMP_01.jpg

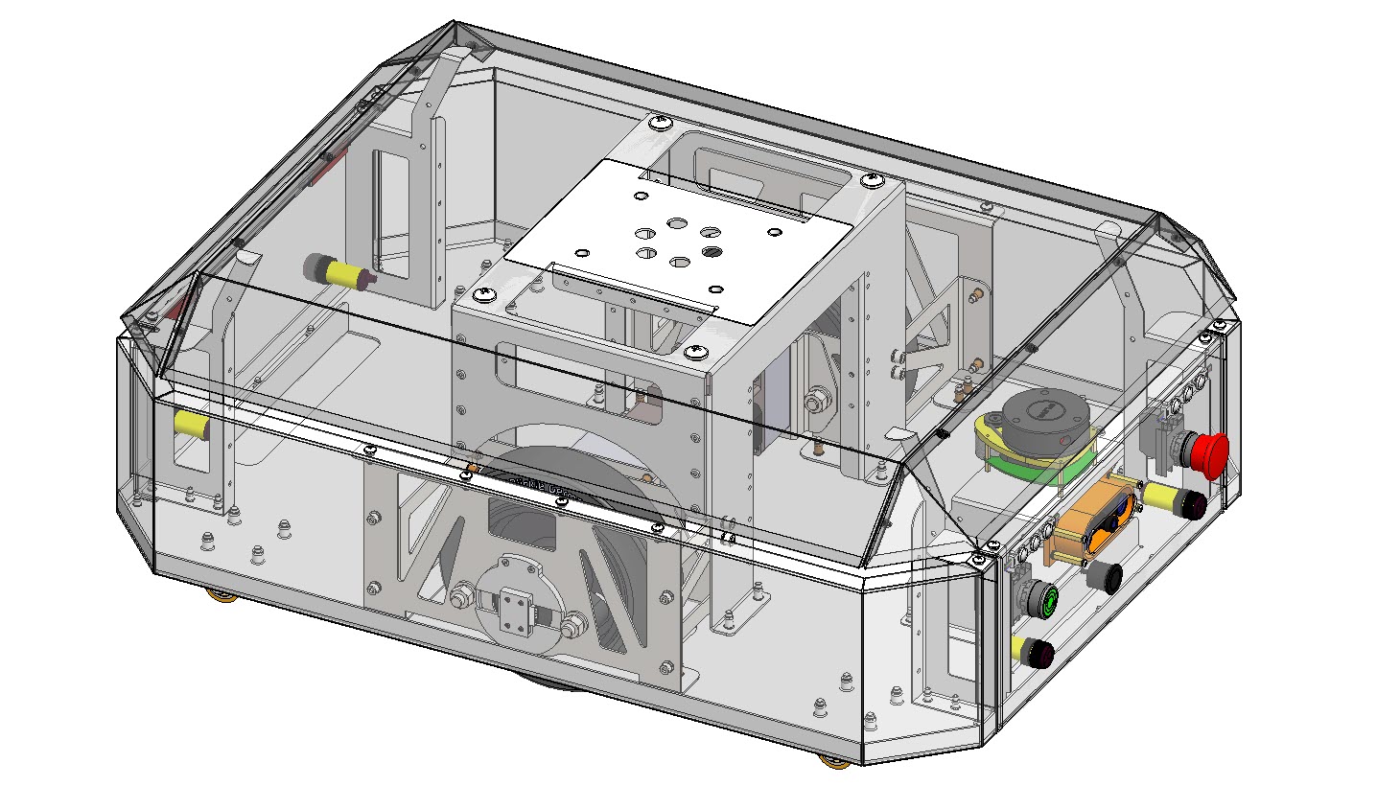
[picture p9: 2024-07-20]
docs/hardware/pictures/AMR_transparent.jpg

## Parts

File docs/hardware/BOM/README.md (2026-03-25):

# Bill of Materials (BOM) repository

## Overview

This document provides a comprehensive list of all assemblies and their corresponding files in the BOM repository. It also includes details on sheet metal parts, fasteners, technological operations, and origin components.

## Sheet metal parts

Sheet metal parts are subject to production variations. The current designs are based on the following coefficients and radii:

- **Coefficient (K):** 0.47
- **Sheet metal specifications:**
  - **0.8 mm Sheet:** Radius (R) = 1.2
  - **1.2 mm Sheet:** Radius (R) = 1.5
  - **2.0 mm Sheet:** Radius (R) = 2.4

### Post-production

- Parts may be painted after bending.
- Riveting nuts can be installed before painting if the threaded part is protected from the coating.
- Screws installed without lock washers should be secured with a thread lock (e.g., Loxeal 55-03).

**Note:** All components are highly interconnected and their functionality is dependent on one another.

## MMP - Multipurpose Mobile Platforms

### List of fasteners and quantities

Detailed information on fasteners and their quantities used in assemblies is listed in the corresponding sections.

### Technological operations

Each assembly comes with a list of required technological operations. Ensure that all operations are followed as specified.

## Origin components

The following components are used in the assemblies:

- **Heavy duty drive wheel:** Blickle GEVN 200/30H7
- **Light duty swivel castor:** Blickle LPA-VSTH 35K
- **Oval flange bearing units:**
  - REXNORD UCFL 205 C 655472 (d25)
  - REXNORD UCFL 206 C 666412 (d30)
- **Rivet nuts:**
  - M4 Blind Rivet Nut - Round Thin - Stainless Steel
  - M5 Blind Rivet Nut - Round Thin - Stainless Steel
  - M6 Blind Rivet Nut - Round Thin - Stainless Steel
  - M8 Blind Rivet Nut - Round Thin - Stainless Steel
- **Feather keys:**
  - 4x4x25 DIN 6885-UNI 6604 (formerly ISO 773)
  - 8x7x28 DIN 6885-UNI 6604 (formerly ISO 773)
- **Screwed spacer sleeve:** TFF-M3/25 FIX&FASTEN
- **BLDC Motor:** Z4BLD60-24GN-30S/4GN 25K 
- **Laser range scanner:** RPLIDAR A1-A1M8
- **Camera module:** NVision Assem
- **Proximity sensor:** E18-D80NK
- **US sensor:** JSN-SR04T
- **LED module:** 3 LED RGB Module 0.72W SWP

__________________________________________________________

# OpenAMR – Preliminary Electronics Bill of Materials (BOM)

## Overview

This Bill of Materials preliminary defines the electronics used in the OpenAMR development platform.  
The system follows a two-layer architecture:

- **High-level control**: Raspberry Pi 5 (ROS2, navigation, perception, UI)  
- **Real-time control**: Teensy 4.0 (motor control, encoders, IMU)  

The setup is designed for differential drive mobile robot development and software validation.

---

## Core Computing

| Item | Model | Qty | Description |
|---|---|-----|---|
| Main Computer | Raspberry Pi 5 (8GB) | 1 | High-level controller running ROS2, SLAM, navigation, and UI |
| Microcontroller | Teensy 4.0 | 1 | Real-time controller for motors, sensors, and low-level logic |
| Communication | USB cable (USB-A ↔ Micro USB / USB-C) | 1 | Serial communication between Raspberry Pi and Teensy |

---

## Drive System

| Item | Model | Qty | Description |
|---|---|-----|---|
| BLDC Motor | ZDBLD60-24GN-30S | 2 | 24V BLDC motor for differential drive |
| Gearbox | 4GN 25K | 2 | Gear reduction for torque increase |
| Motor Driver | ZBLD-C20-120L2R | 2 | BLDC motor driver (PWM speed control, digital direction control) |

---

## Feedback Sensors

| Item | Model | Qty | Description |
|---|---|-----|---|
| Magnetic Encoder | AS5040 | 2 | Wheel position sensing for odometry (Quadrature (A/B) or SPI interface) |
| IMU | MPU6050 | 1 | 6-axis inertial measurement unit (accelerometer + gyroscope, I2C) |

---

## Perception Sensors

| Item | Model | Qty | Description |
|---|---|-----|---|
| LiDAR | RPLIDAR A1 | 1 | 2D laser scanner for SLAM and obstacle detection (USB) |
| Camera | Raspberry Pi Camera Module / Arducam IMX219 | 1 | Vision sensor for docking and computer vision tasks (CSI interface) |

---

## Power System

| Item | Model | Qty | Description |
|---|---|-----|---|
| Battery | 24V Li-ion / LiFePO4 pack | 1 | Main power source for motors and electronics |
| DC-DC Converter | LM2596 Buck Converter (24V → 5V, ≥5A) | 1 | Power supply for Raspberry Pi |
| DC-DC Converter | DROK 24V → 5V/12V Step-Down Module | 1 | Power supply for sensors and auxiliary electronics |
| Protection | Inline fuse (rated above motor current) | 1 | Overcurrent protection on main power line |
| Safety | Emergency stop switch | 1 | Manual power cutoff for safety |

---

## Interfaces and Integration

| Item | Model | Qty | Description |
|---|---|-----|---|
| Prototyping Board | Breadboard / Perfboard | 1 | Temporary wiring platform (used until custom PCB is developed) |
| Power Distribution | Terminal blocks / distribution bus | 1 set | Power routing for 24V and low-voltage lines |
| Wiring | Motor cables, signal wires, connectors | 1 set | Electrical connections between components |

---

## Alternative Drive Option (ZL Tech)

| Item | Model | Qty | Description |
|---|---|-----|---|
| Hub Motor | ZLLG80ASM250-L | 2 | Integrated BLDC motor with built-in encoder |
| Driver | ZLAC8015D | 1–2 | Motor controller with RS485/CAN interface |

---

## System Interfaces Summary

- Raspberry Pi ↔ Teensy: USB Serial  
- Teensy ↔ Motor Drivers: PWM (speed) + Digital IO (direction)  
- Teensy ↔ Encoders: Quadrature (A/B) or SPI interface  
- Teensy ↔ IMU: I2C  
- Raspberry Pi ↔ LiDAR: USB  
- Raspberry Pi ↔ Camera: CSI  

---

## Notes

- The system is designed for modular expansion and hardware replacement.  
- Breadboard or perfboard is used for initial prototyping before designing a custom carrier PCB.  
- All components are selected to support ROS2-based mobile robotics development.  





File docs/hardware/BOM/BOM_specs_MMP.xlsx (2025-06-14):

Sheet: Сomposition
 |  |  |  |  |  |  |  |  | MMP - Multipurpose mobile platform - parts and assemblies
3D-model | PDF | Dxf | STEP | Drawing | 3D-PDF | № | Part number |  |  | Description | Q-ty for 1 platform | Material | Covering | Notes
TRUE | FALSE | FALSE | TRUE | FALSE | FALSE | 0.0.0 | MMP.00.00.00.000 |  |  | Multipurpose mobile platform | 1
TRUE | TRUE | TRUE | TRUE | TRUE | FALSE | 0.0.1 | MMP.00.00.00.001 |  |  | Front panel | 1 | Steel EN 1.0114, s2 | RAL9016
TRUE | TRUE | TRUE | TRUE | TRUE | FALSE | 0.0.2 | MMP.00.00.00.002 |  |  | Back panel | 1 | Steel EN 1.0114, s2 | RAL9016
TRUE | TRUE | TRUE | TRUE | TRUE | FALSE | 0.0.3 | MMP.00.00.00.003 |  |  | Side panel | 2 | Steel EN 1.0114, s0,8 | RAL9016
TRUE | FALSE | FALSE | TRUE | FALSE | FALSE | 0.0.4 | РТ1.00.00.032 |  |  | Camera upper body | 1 |  |  | 3d-printing
TRUE | FALSE | 0 | TRUE | FALSE | TRUE | 1 | MMP.01.00.00.000 |  |  | Cover assembly | 1
TRUE | TRUE | TRUE | TRUE | TRUE | FALSE | 1.1 |  | MMP.01.00.00.001 |  | Cover | 1 | Steel EN 1.0114, s0,8 | RAL9016
TRUE | TRUE | TRUE | TRUE | TRUE | FALSE | 1.2 |  | MMP.01.00.00.002 |  | Cover flange | 2 | Steel EN 1.0114, s0,8 | RAL9016
TRUE | FALSE | 0 | TRUE | FALSE | TRUE | 2 | MMP.02.00.00.000 |  |  | Base assembly | 1
TRUE | TRUE | TRUE | TRUE | TRUE | FALSE | 2.1 |  | MMP.02.00.00.001 |  | Base |  | Steel EN 1.0114, s2 | RAL9016
TRUE | FALSE | FALSE | TRUE | FALSE | TRUE | 3 | MMP.03.00.00.000 |  |  | Wheel assembly | 2
TRUE | TRUE | TRUE | TRUE | TRUE | FALSE | 3.1 |  | MMP.03.00.00.001 |  | Wheel bracket outer | 2 | Steel EN 1.0114, s2 | RAL9016 | Threaded holes (М3, М4)
TRUE | TRUE | TRUE | TRUE | TRUE | FALSE | 3.2 |  | MMP.03.00.00.002 |  | Wheel bracket inner | 2 | Steel EN 1.0114, s2 | RAL9016 | Threaded holes (М4)
TRUE | TRUE | TRUE | TRUE | TRUE | FALSE | 3.3 |  | MMP.03.00.00.003 |  | Motor bracket | 2 | Steel EN 1.0114, s2 | RAL9016
TRUE | TRUE | FALSE | TRUE | TRUE | FALSE | 3.4 |  | MMP.03.00.00.004 |  | Drive shaft | 2 | Steel 37Cr4
TRUE | FALSE | FALSE | TRUE | FALSE | TRUE | 3.5 |  | РТ1.00.00.240 |  | Magnetic encoder | 2
TRUE | FALSE | FALSE | TRUE | FALSE | FALSE | 3.5.1 |  |  | РТ1.00.00.241 | Adapter | 2 |  |  | 3d-printing
TRUE | FALSE | FALSE | TRUE | FALSE | FALSE | 3.5.2 |  |  | РТ1.00.00.242 | Bracket | 2 |  |  | 3d-printing
TRUE | FALSE | FALSE | TRUE | FALSE | FALSE | 3.5.3 |  |  | РТ1.00.00.243 | Cover | 2 |  |  | 3d-printing
TRUE | FALSE | FALSE | TRUE | FALSE | TRUE | 4 | MMP.04.00.00.000 |  |  | Center bracket assembly | 1
TRUE | TRUE | TRUE | TRUE | TRUE | FALSE | 4.1 |  | MMP.04.00.00.001 |  | Center bracket |  | Steel EN 1.0114, s2 | RAL9016
TRUE | FALSE | FALSE | TRUE | FALSE | TRUE | 5 | MMP.05.00.00.000 |  |  | Support assembly | 2
TRUE | TRUE | TRUE | TRUE | TRUE | FALSE | 5.1 |  | MMP.05.00.00.001 |  | Support |  | Steel EN 1.0114, s1,2 | RAL9016
TRUE | FALSE | FALSE | TRUE | FALSE | TRUE | 6 | MMP.05.00.00.000-01 |  |  | Support assembly | 2
TRUE | TRUE | TRUE | TRUE | TRUE | FALSE | 6.1 |  | MMP.05.00.00.001-01 |  | Support |  | Steel EN 1.0114, s1,2 | RAL9016
TRUE | FALSE | FALSE | TRUE | FALSE | TRUE | 7 | MMP.07.00.00.000 |  |  | Lidar support assembly | 1
TRUE | TRUE | TRUE | TRUE | TRUE | FALSE | 7.1 |  | MMP.07.00.00.001 |  | Lidar support |  | Steel EN 1.0114, s1,2 | RAL9016
 |  |  |  |  |  |  | - 3D-printed part

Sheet: Components
№ | Description |  | Q-ty for 1 platform, pcs | Link | Part No. | Additional info
1 | Heavy duty drive wheel | Blickle GEVN 200/30H7 | 2 | Link (https://www.blickle.com/product/GEVN-200-30H7-754372) | 4047526113377 | Catalogue (https://www.blickle.com/products/wheel-castor-series/drive-wheels-hub-fitting-wheels-ground-wheels/drive-wheels)
2 | Light duty swivel castor | Blickle LPA-VSTH 35K | 4 | Link (https://www.blickle.com/product/LPA-VSTH-35K-603175) | 4047526603175
3 | Oval flange bearing units | REXNORD UCFL 205 C 655472 (d25) | 2 | Link (http://www.intergear.eu/produkty/dopravniky/rexnord/10Oval-flang-bearing.pdf) | 655472
4 | Oval flange bearing units | REXNORD UCFL 206 C 666412 (d30) | 2 | Link (http://www.intergear.eu/produkty/dopravniky/rexnord/10Oval-flang-bearing.pdf) | 666412
5 | Rivet Nut - M4 | Blind Rivet Nut - Round Thin - Stainless Steel - M4 | 58 | Link (https://www.insertsdirect.com/product/blind-rivet-nut-round-thin-stainless-steel-m4-48) | 100 - 5802159
6 | Rivet Nut - M5 | Blind Rivet Nut - Round Thin - Stainless Steel - M5 | 48 | Link (https://www.insertsdirect.com/product/blind-rivet-nut-round-thin-stainless-steel-m5-49) | 100 - 5802287
7 | Rivet Nut - M6 | Blind Rivet Nut - Round Thin - Stainless Steel - M6 | 16 | Link (https://www.insertsdirect.com/product/blind-rivet-nut-round-thin-stainless-steel-m6-50) | 100 - 5802253
8 | Rivet Nut - M8 | Blind Rivet Nut - Round Thin - Stainless Steel - M8 | 8 | Link (https://www.insertsdirect.com/product/blind-rivet-nut-round-thin-stainless-steel-m8-51) | 100 - 5802182
9 | Feather key | Feather key 4x4x25 DIN 6885-UNI 6604 (former ISO 773) | 2 | Link (http://opis.cz/chiavette/pdf/DIN6885.pdf)
10 | Feather key | Feather key 8x7x28 DIN 6885-UNI 6604 (former ISO 773) | 2
11 | Screwed spacer sleeve | TFF-M3/25 FIX&FASTEN | 4 | Link (https://www.tme.eu/gb/details/tff-m3_25/metal-spacers/fix-fasten/)
12 | BLDC motor | Z4BLD60-24GN-30S/4GN 25K | 2
13 | Laser Range Scanner | RPLIDAR A1-A1M8 | 1 | Link (https://www.slamtec.com/en/Lidar/A1)
14 | Camera | Camera Module NVision Assem | 1
14 | Proximity Sensor | E18-D80NK | 4 | Link (https://datasheetspdf.com/pdf/1311840/tinkbox/E18-D80NK/1)
15 | US Sensor | JSN-SR04T | 1
16 | LED module | 3 LED RGB Module 0.72W SWP | 2

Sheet: Applicability of fasteners
MMP - Applicability of fasteners
№ | Part number | Description | Q-ty, pcs | 3D PDF | Blind Rivet Nut - Round Thin - Stainless Steel - M4 | Blind Rivet Nut - Round Thin - Stainless Steel - M5 | Blind Rivet Nut - Round Thin - Stainless Steel - M6 | Blind Rivet Nut - Round Thin - Stainless Steel - M8 | Blind rivet Al/St 4,0х8, DIN 7337 | Screw М4x16 DIN 912 | Screw М5x20 DIN 912 | Screw М5x70 DIN 912 | Screw М6x20 DIN 912 | Screw М10x45 DIN 912 | Screw М3x12 DIN 965 | Screw М3x8 DIN 966 | Screw М3x12 DIN 967 | Screw М4x12 DIN 967 | Screw М4x16 DIN 967 | Screw М8x25 DIN 967 | Screw М2x8 DIN 7985 | Screw М2x16 DIN 7985 | Screw М2,5x6 DIN 7985 | Screw М3x8 DIN 7985 | Screw М4x16 DIN 7985 | Nut M2 DIN 934 | Nut M3 DIN 934 | Nut M10 DIN 934 | Washer 2 DIN 125 | Washer 2,5 DIN 125 | Washer 3 DIN 125 | Washer 4 DIN 125 | Washer 5 DIN 125 | Washer 6 DIN 125 | Washer 8 DIN 125 | Washer 10 DIN 125 | Spring lock washer 2 DIN 7980 | Spring lock washer 2,5 DIN 7980 | Spring lock washer 3 DIN 7980 | Spring lock washer 4 DIN 7980 | Spring lock washer 5 DIN 7980 | Spring lock washer 6 DIN 7980 | Spring lock washer 10 DIN 7980 | Large size washer 4 DIN 9021 | Screwed spacer sleeve TFF-M3/25 | Feather key 4x4x25 DIN 6885-UNI 6604 (former ISO 773) | Feather key 8x7x28 DIN 6885-UNI 6604 (former ISO 773)
1.1 | Main assembly | Camera to Front panel |  |  |  |  |  |  |  |  |  |  |  |  |  | 4 | 4 |  |  |  |  | 4 |  |  |  | 4 |  |  | 4 |  | 16 |  |  |  |  |  | 4 |  |  |  |  |  |  |  | 4
1.2 |  | Cover to Center bracket |  |  |  |  |  |  |  |  |  |  |  |  |  |  |  |  |  | 4 |  |  |  |  |  |  |  |  |  |  |  |  |  |  | 4
1.3 |  | Lidar to support assembly |  |  |  |  |  |  |  |  |  |  |  |  |  |  |  |  |  |  |  |  | 4 |  |  |  |  |  |  | 4 |  |  |  |  |  |  |  | 4
1.4 |  | Lidar support assembly to base |  |  |  |  |  |  |  |  |  |  |  |  |  |  |  |  |  |  |  |  |  |  | 4 |  |  |  |  |  |  | 4 |  |  |  |  |  |  |  | 4
1.5 |  | Center bracket to base |  |  |  |  |  |  |  |  | 16 |  |  |  |  |  |  |  |  |  |  |  |  |  |  |  |  |  |  |  |  |  | 16 |  |  |  |  |  |  |  | 16
1.6 |  | Side panels |  |  |  |  |  |  |  |  |  |  |  |  |  |  |  | 32
1.7 |  | Front panel - up |  |  |  |  |  |  |  |  |  |  |  |  |  |  |  | 4
1.8 |  | Front panel - down |  |  |  |  |  |  |  |  |  |  |  |  |  |  |  |  | 10
1.9 |  | Support assemblies to base |  |  |  |  |  |  |  | 8 |  |  |  |  |  |  |  |  |  |  |  |  |  |  |  |  |  |  |  |  |  |  |  |  |  |  |  |  |  | 8 |  |  |  | 8
1.10 |  | Light duty swivel castors to base |  |  |  |  |  |  |  |  |  |  | 16 |  |  |  |  |  |  |  |  |  |  |  |  |  |  |  |  |  |  |  |  | 16 |  |  |  |  |  |  |  | 16
1.11 |  | Wheel assemblies to base |  |  |  |  |  |  |  |  | 16 |  |  |  |  |  |  |  |  |  |  |  |  |  |  |  |  |  |  |  |  |  | 16 |  |  |  |  |  |  |  | 16
2 | MMP.01.00.00.000 | Cover assembly | 1 |  |  |  |  |  |  |  |  |  |  |  |  |  |  |  |  |  |  |  |  | 10 |  |  | 10 |  |  |  | 20 |  |  |  |  |  |  |  | 10
3 | MMP.02.00.00.000 | Base assembly | 1 |  | 26 |  | 16
4 | MMP.03.00.00.000 | Wheel assembly | 2 |  | 8 | 40 |  |  |  |  | 8 | 8 |  | 8 | 4 |  |  |  |  |  |  |  |  |  |  |  | 4 | 8 |  |  |  |  | 16 |  |  | 12 |  |  |  |  |  |  | 8 |  |  | 2 | 2
4.1 | РТ1.00.00.240 | Magnetic encoder | 2 |  |  |  |  |  |  |  |  |  |  |  |  |  |  |  |  |  | 8 |  |  |  |  | 8
6 | MMP.04.00.00.000 | Center bracket assembly | 1 |  |  | 8 |  | 8 | 16
7 | MMP.05.00.00.000 | Support assembly | 2 |  | 10
8 | MMP.05.00.00.000-01 | Support assembly | 2 |  | 10
9 | MMP.07.00.00.000 | Lidar support assembly | 1 |  | 4
 |  | Total: |  |  | 58 | 48 | 16 | 8 | 16 | 8 | 40 | 8 | 16 | 8 | 4 | 4 | 4 | 36 | 10 | 4 | 8 | 4 | 4 | 10 | 4 | 12 | 14 | 8 | 4 | 4 | 36 | 4 | 48 | 16 | 4 | 12 | 4 | 4 | 10 | 12 | 32 | 16 | 8 | 8 | 4 | 2 | 2

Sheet: General list of fasteners
№ | Description | Q-ty, pcs
1 | Screw М4x16 DIN 912 | 8
2 | Screw М5x20 DIN 912 | 40
3 | Screw М5x70 DIN 912 | 8
4 | Screw М6x20 DIN 912 | 16
5 | Screw М10x45 DIN 912 | 8
6 | Screw М3x12 DIN 965 | 4
7 | Screw М3x8 DIN 966 | 4
8 | Screw М3x12 DIN 967 | 4
9 | Screw М4x12 DIN 967 | 36
10 | Screw М4x16 DIN 967 | 10
11 | Screw М8x25 DIN 967 | 4
12 | Screw М2x8 DIN 7985 | 8
13 | Screw М2x16 DIN 7985 | 4
14 | Screw М2,5x6 DIN 7985 | 4
15 | Screw М3x8 DIN 7985 | 10
16 | Screw М4x16 DIN 7985 | 4
17 | Nut M2 DIN 934 | 12
18 | Nut M3 DIN 934 | 14
19 | Nut M10 DIN 934 | 8
20 | Blind Rivet Nut - Round Thin - Stainless Steel - M4 | 58
21 | Blind Rivet Nut - Round Thin - Stainless Steel - M5 | 48
22 | Blind Rivet Nut - Round Thin - Stainless Steel - M6 | 16
23 | Blind Rivet Nut - Round Thin - Stainless Steel - M8 | 8
24 | Blind rivet Al/St 4,0х8, DIN 7337 | 16
25 | Washer 2 DIN 125 | 4
26 | Washer 2,5 DIN 125 | 4
27 | Washer 3 DIN 125 | 36
28 | Washer 4 DIN 125 | 4
29 | Washer 5 DIN 125 | 48
30 | Washer 6 DIN 125 | 16
31 | Washer 8 DIN 125 | 4
32 | Washer 10 DIN 125 | 12
33 | Spring lock washer 2 DIN 7980 | 4
34 | Spring lock washer 2,5 DIN 7980 | 4
35 | Spring lock washer 3 DIN 7980 | 10
36 | Spring lock washer 4 DIN 7980 | 12
37 | Spring lock washer 5 DIN 7980 | 32
38 | Spring lock washer 6 DIN 7980 | 16
39 | Spring lock washer 10 DIN 7980 | 8
40 | Large size washer 4 DIN 9021 | 8
41 | Feather key 4x4x25 DIN 6885-UNI 6604 (former ISO 773) | 2
42 | Feather key 8x7x28 DIN 6885-UNI 6604 (former ISO 773) | 2

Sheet: Assembly nuances
№ | Description
1 | Sheet metal parts vary by production. Currently, the parts are designed for the following coefficients and radii: K=0.47: sheet 0.8 mm - R=1.2; sheet 1.2 mm - R=1.5; sheet 2.0 mm - R=2.4.
2 | After bending, parts could be painted.
3 | After painting, we install riveting nuts. It is allowed to install riveting nuts before painting, provided that the threaded part of the nuts is protected from coating.
4 | Screws installed without lock washers - fix with a thread lock (eg Loxeal 55-03).
5 | There may be nuances with block bearings. All details are strongly interconnected and depend on each other.

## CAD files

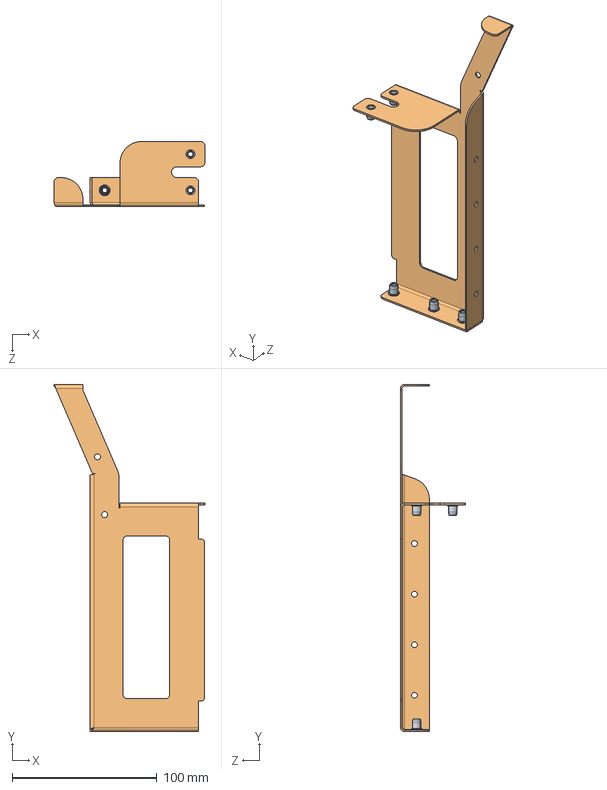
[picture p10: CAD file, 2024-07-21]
docs/hardware/CAD_files/production_files/MMP.05.00.00.000 Support assembly.STEP
104.3 x 240.0 x 45.0 mm
Ãàéêà êëåïàëüíàÿ Ì4_0,5-2 óì. ïîòàé, ñòàëü_ãáâ.  1,2 ¬¬ x 5
MMP.05.00.00.001 Support_�� 㬮�砭��

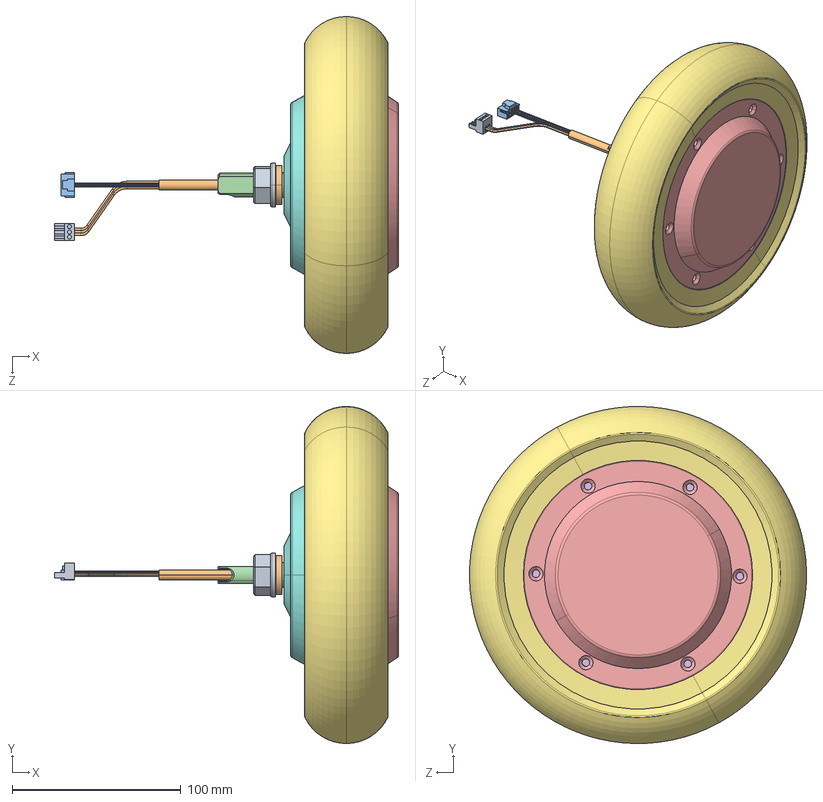
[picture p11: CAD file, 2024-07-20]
docs/hardware/datasheets/ZLTech/wheel_ZLLG80ASM250/ZLLG80ASM250-L V3.0单出轴.SLDASM
204.4 x 200.0 x 199.9 mm
5cun-1.1.stp
5G-shuang_1.1.stp
零件1.1.2.stp
零件1.stp
6.5C-QDG-KaiMo.stp
零件1.1.stp
零件2.1.1.stp
MANIFOLD_SOLID_BREP_6700.stp
零件1.1.2.1.stp
Part1.2.stp

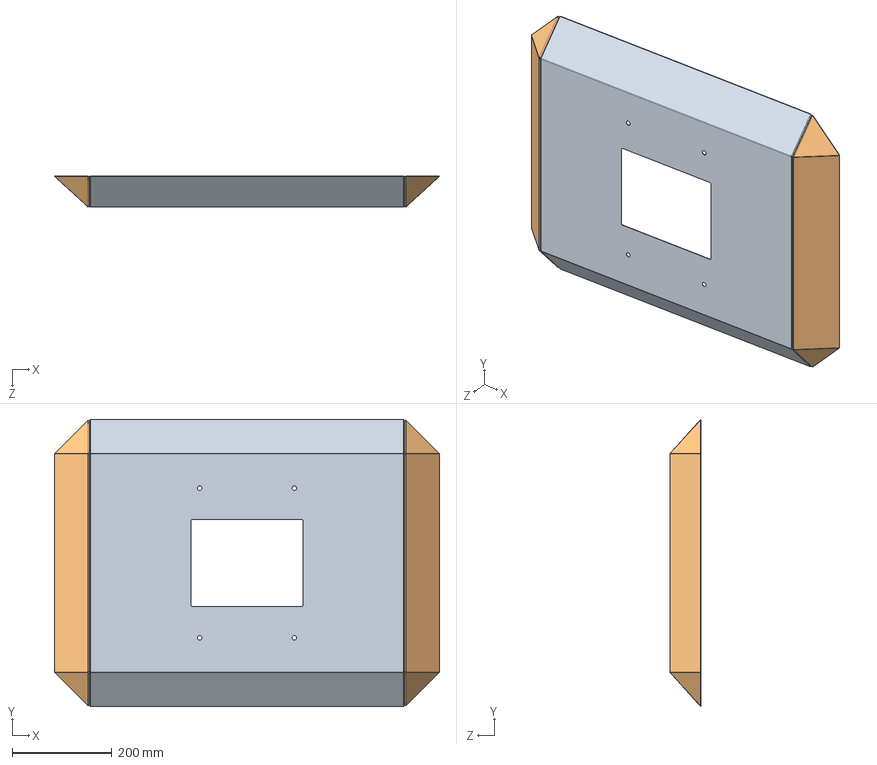
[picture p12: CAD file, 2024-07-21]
docs/hardware/CAD_files/production_files/MMP.01.00.00.000 Cover assembly.STEP
771.6 x 575.6 x 63.0 mm
MMP.01.00.00.001 Cover_00
MMP.01.00.00.002 Cover flange_00 x 2
Âèíò DIN 7985 (öèë.)_ISO 7045 - M3 x 8 - Z --- 8C x 10
Ãàéêà DIN 934_Hexagon Nut ISO - 4032 - M3 - D - C x 10
ﾘ琺矜 DIN 125_Washer DIN 125 - A 3.2 x 20
Øàéáà DIN 7980 (ïðóæèííàÿ)_˜ ©¡ 3 ƒŽ‘’ 6402-70 x 10

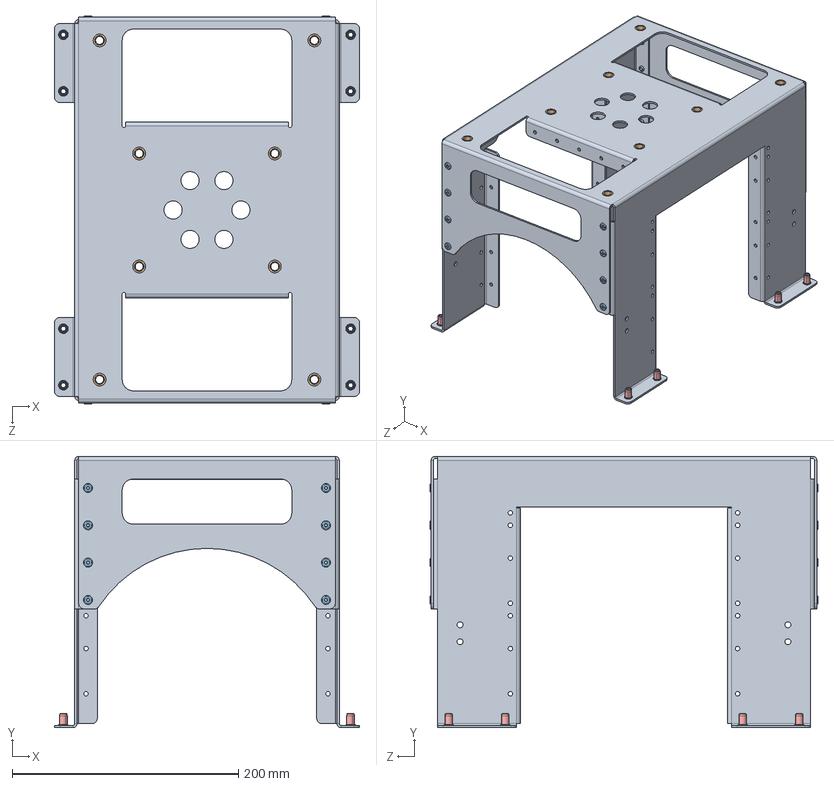
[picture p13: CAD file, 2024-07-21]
docs/hardware/CAD_files/production_files/MMP.04.00.00.000 Center bracket assembly.STEP
270.0 x 240.0 x 343.2 mm
MMP.04.00.00.001 Center bracket_�� 㬮�砭��
Ãàéêà êëåïàëüíàÿ Ì8_0,5-2,5 óì. ïîòàé, ñòàëü_ãáâ.  2 ¬¬ x 8
Çàêë¸ïêà âûòÿæíàÿ 4,0 DIN 7337_ 4,1 x 16
Ãàéêà êëåïàëüíàÿ Ì5_0,5-2 óì. ïîòàé, ñòàëü_ãáâ.  2 ¬¬ x 8

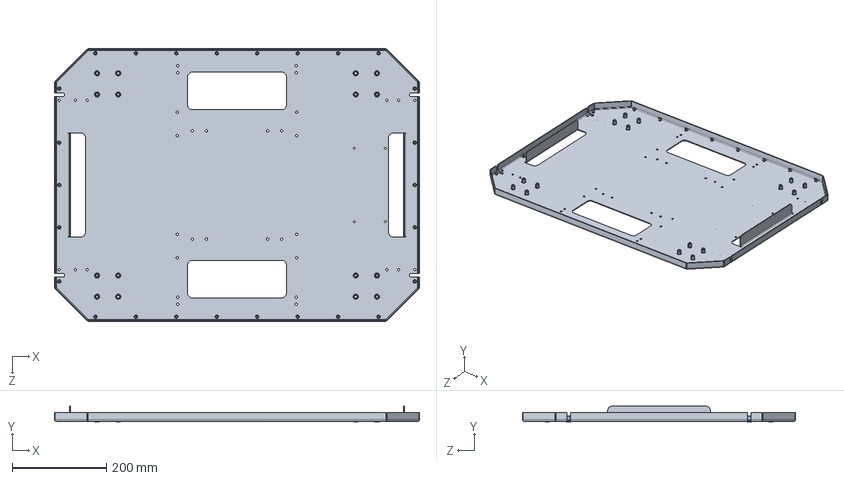
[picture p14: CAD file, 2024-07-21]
docs/hardware/CAD_files/production_files/MMP.02.00.00.000 Base assembly.STEP
776.0 x 33.2 x 580.0 mm
MMP.02.00.00.001 Base_�� 㬮�砭��
Ãàéêà êëåïàëüíàÿ Ì4_0,5-2 óì. ïîòàé, ñòàëü_ãáâ.  2 ¬¬ x 26
Ãàéêà êëåïàëüíàÿ Ì6_0,5-2,5 óì. ïîòàé, ñòàëü_ãáâ.  1,5 ¬¬ x 16

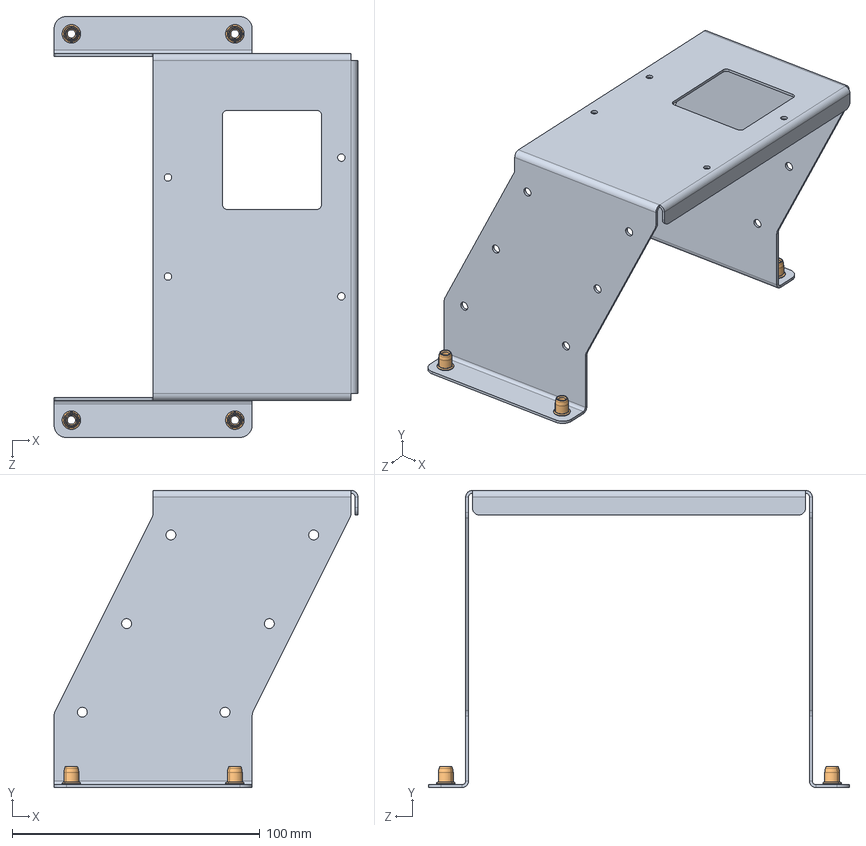
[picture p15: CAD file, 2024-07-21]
docs/hardware/CAD_files/production_files/MMP.07.00.00.000 Lidar support assembly.STEP
122.7 x 120.0 x 170.0 mm
MMP.07.00.00.001 Lidar support_�� 㬮�砭��
Ãàéêà êëåïàëüíàÿ Ì4_0,5-2 óì. ïîòàé, ñòàëü_ãáâ.  1,2 ¬¬ x 4

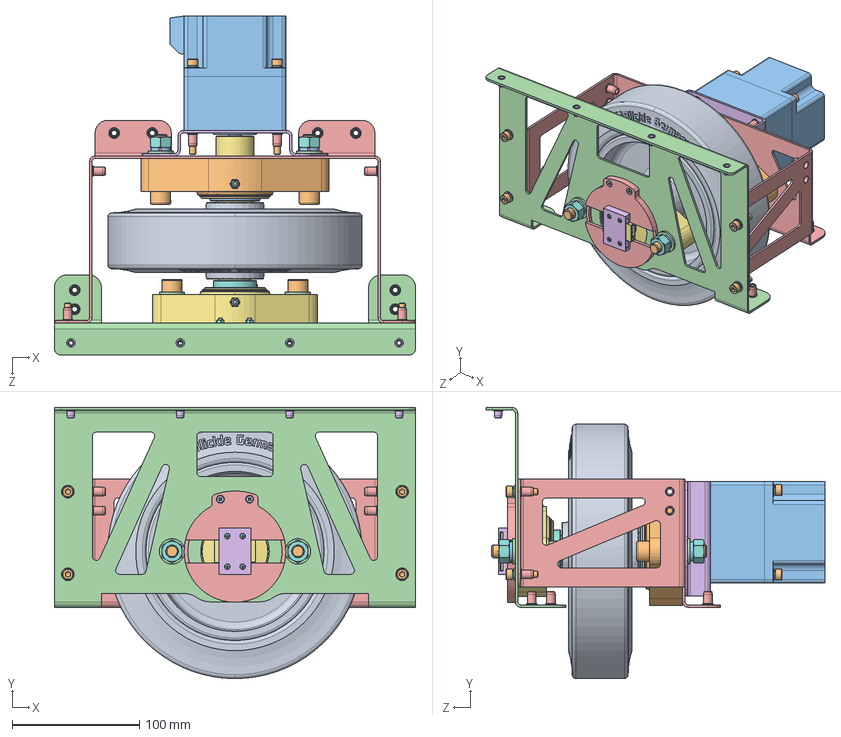
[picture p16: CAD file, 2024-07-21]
docs/hardware/CAD_files/production_files/MMP.03.00.00.000 Wheel assembly.SLDASM
284.0 x 213.2 x 266.5 mm
GEVN_200_30H7_G15
РТ1.00.00.217 Шпонка
Шпонка 3-4x4x25 ГОСТ 23360-78
PT1.00.00.241 Adapter
PT1.00.00.242 Bracket
PT1.00.00.243 Cover
Плата магнитного энкодера
Винт М2-6gx8.48 DIN 7985 x 4
Гайка M2 DIN 934 x 4
Сердечник BMN-35H
Мотор-редуктор Z4BLD60-24GU серия 80
MMP.03.00.00.001 Wheel bracket outer
MMP.03.00.00.002 Wheel bracket inner
MMP.03.00.00.003 Motor bracket
MMP.03.00.00.004 Drive shaft
Гайка DIN 934 x 6
Винт DIN 965 (потай) x 2
Винт DIN 912 (вн. шест.) x 12
Шайба DIN 7980 (пружинная) x 12
Шайба DIN 125 x 14
Гайка клепальная М5_0,5-2 ум. потай, сталь x 20
Гайка клепальная М4_0,5-2 ум. потай, сталь x 4
Rexnord-UCFL- SUCFL- HCFL- SHCFL-UCFL 205 C-68563_HUB
Rexnord-UCFL- SUCFL- HCFL- SHCFL-UCFL 205 C-68563_BEARING
Rexnord-UCFL- SUCFL- HCFL- SHCFL-UCFL 205 C-68563_NIPPLE
Rexnord-UCFL- SUCFL- HCFL- SHCFL-UCFL 206 C-68439_HUB
Rexnord-UCFL- SUCFL- HCFL- SHCFL-UCFL 206 C-68439_BEARING
Rexnord-UCFL- SUCFL- HCFL- SHCFL-UCFL 206 C-68439_NIPPLE

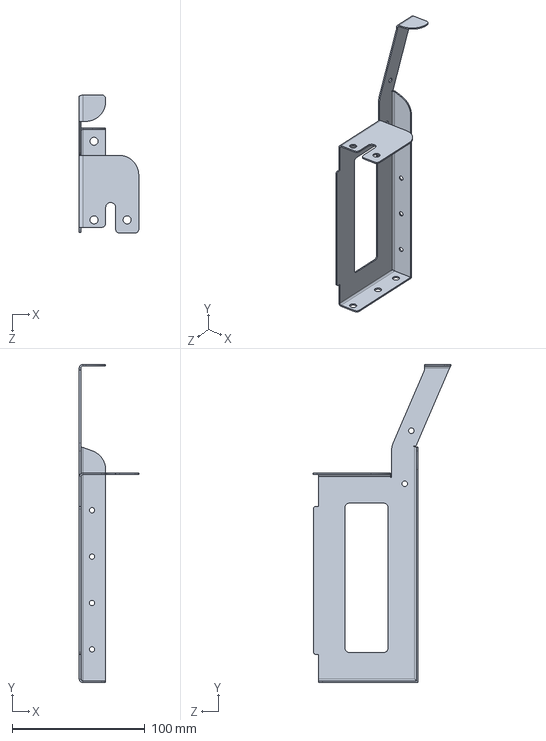
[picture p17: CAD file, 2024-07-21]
docs/hardware/CAD_files/production_files/MMP.05.00.00.001 Support.STEP
45.0 x 240.0 x 104.3 mm

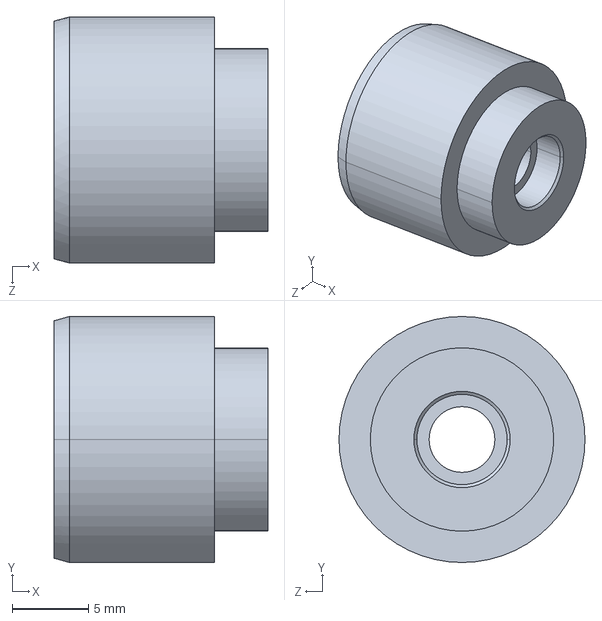
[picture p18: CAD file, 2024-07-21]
docs/hardware/CAD_files/production_files/PT1.00.00.241 Adapter.STEP
14.0 x 16.1 x 16.1 mm

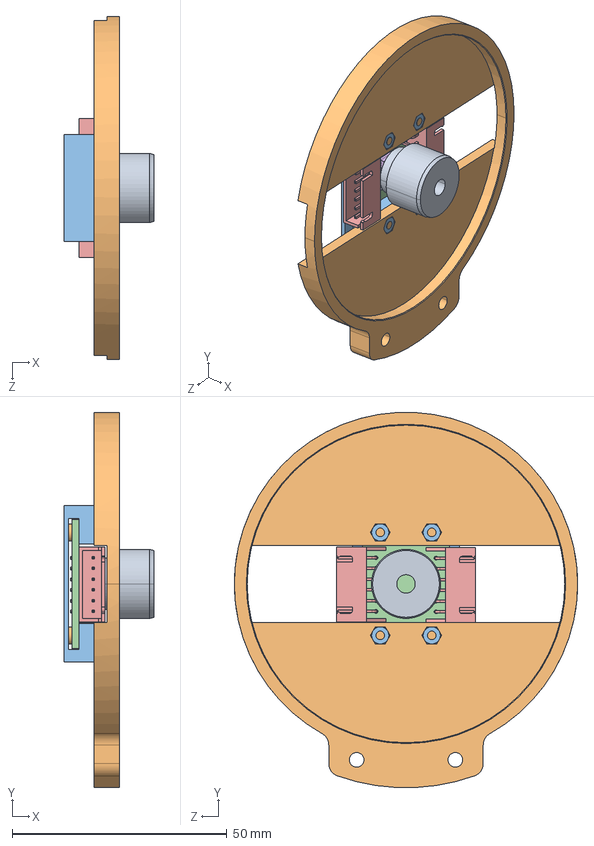
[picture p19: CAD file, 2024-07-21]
docs/hardware/CAD_files/production_files/PT1.00.00.240 Magnetic encoder.STEP
21.0 x 87.4 x 80.0 mm
PT1.00.00.241 Adapter_00
PT1.00.00.242 Bracket_00
PT1.00.00.243 Cover_00
Ïëàòà ìàãíèòíîãî ýíêîäåðà_00
Âèíò Ì2-6gx8.48 DIN 7985_00 x 4
Ãàéêà M2 DIN 934_00 x 4
ﾑ褞蒟韭 BMN-35H_00

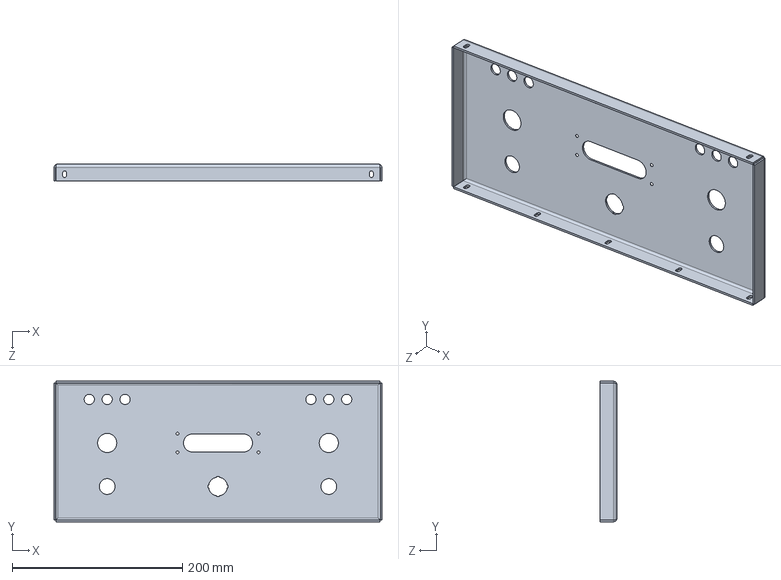
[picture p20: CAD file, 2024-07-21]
docs/hardware/CAD_files/production_files/MMP.00.00.00.001 Front panel.STEP
384.8 x 165.0 x 20.0 mm

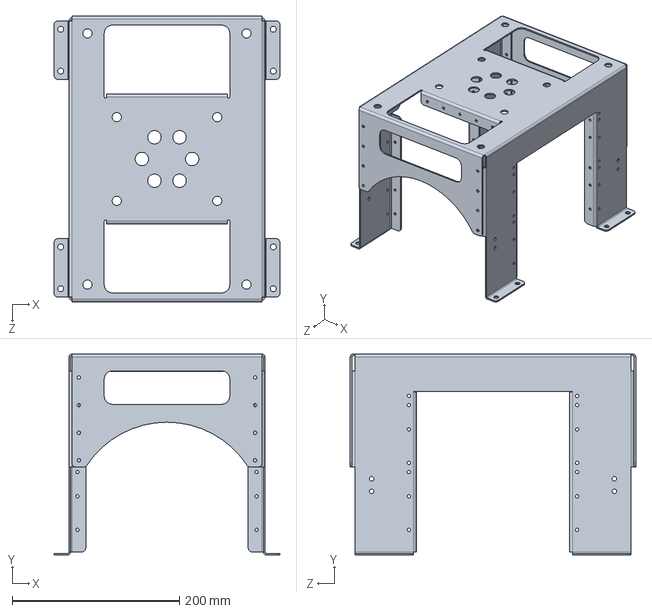
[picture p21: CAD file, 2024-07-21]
docs/hardware/CAD_files/production_files/MMP.04.00.00.001 Center bracket.STEP
270.0 x 240.0 x 341.2 mm

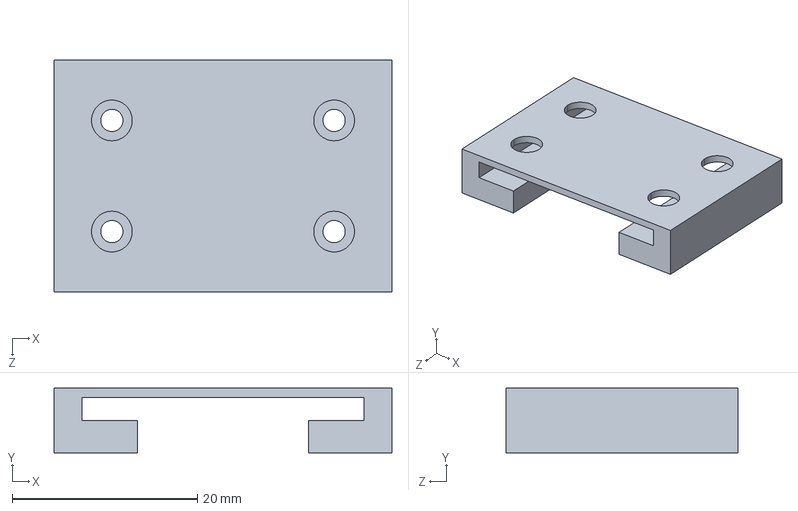
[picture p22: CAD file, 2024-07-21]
docs/hardware/CAD_files/production_files/PT1.00.00.243 Cover.STEP
36.5 x 7.00 x 25.0 mm

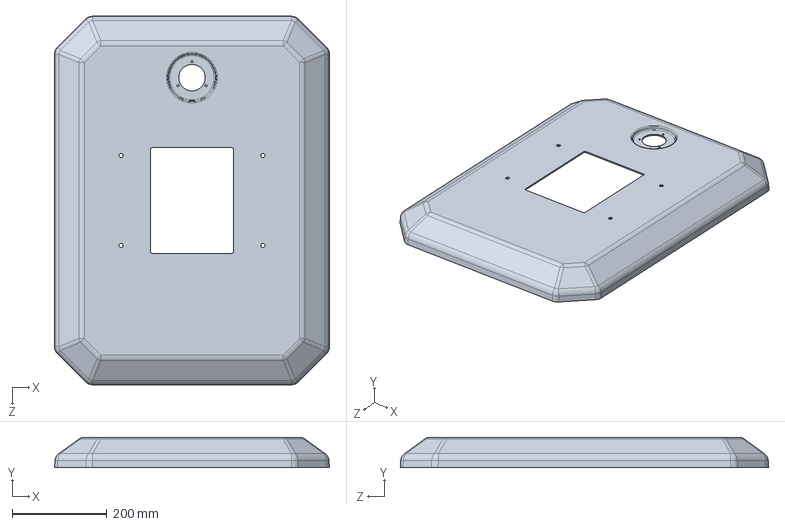
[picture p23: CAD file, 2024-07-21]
docs/hardware/CAD_files/production_files/MMP.00.00.00.004 Plastic cover.STEP
582.0 x 64.0 x 780.0 mm

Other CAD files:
docs/hardware/CAD_files/production_files/MMP.05.00.00.000-01 Support assembly.STEP
docs/hardware/CAD_files/production_files/MMP.05.00.00.001-01 Support.STEP
docs/hardware/CAD_files/production_files/MMP.00.00.00.002 Back panel.STEP
docs/hardware/CAD_files/production_files/MMP.03.00.00.003 Motor bracket.STEP
docs/hardware/CAD_files/production_files/MMP.00.00.00.001 Front panel.DXF
docs/hardware/CAD_files/production_files/MMP.00.00.00.001 Front panel.SLDDRW
docs/hardware/CAD_files/production_files/MMP.00.00.00.001 Front panel.SLDPRT
docs/hardware/CAD_files/production_files/MMP.00.00.00.002 Back panel.DXF
docs/hardware/CAD_files/production_files/MMP.00.00.00.002 Back panel.SLDDRW
docs/hardware/CAD_files/production_files/MMP.00.00.00.002 Back panel.SLDPRT
docs/hardware/CAD_files/production_files/MMP.00.00.00.003 Side panel.DXF
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

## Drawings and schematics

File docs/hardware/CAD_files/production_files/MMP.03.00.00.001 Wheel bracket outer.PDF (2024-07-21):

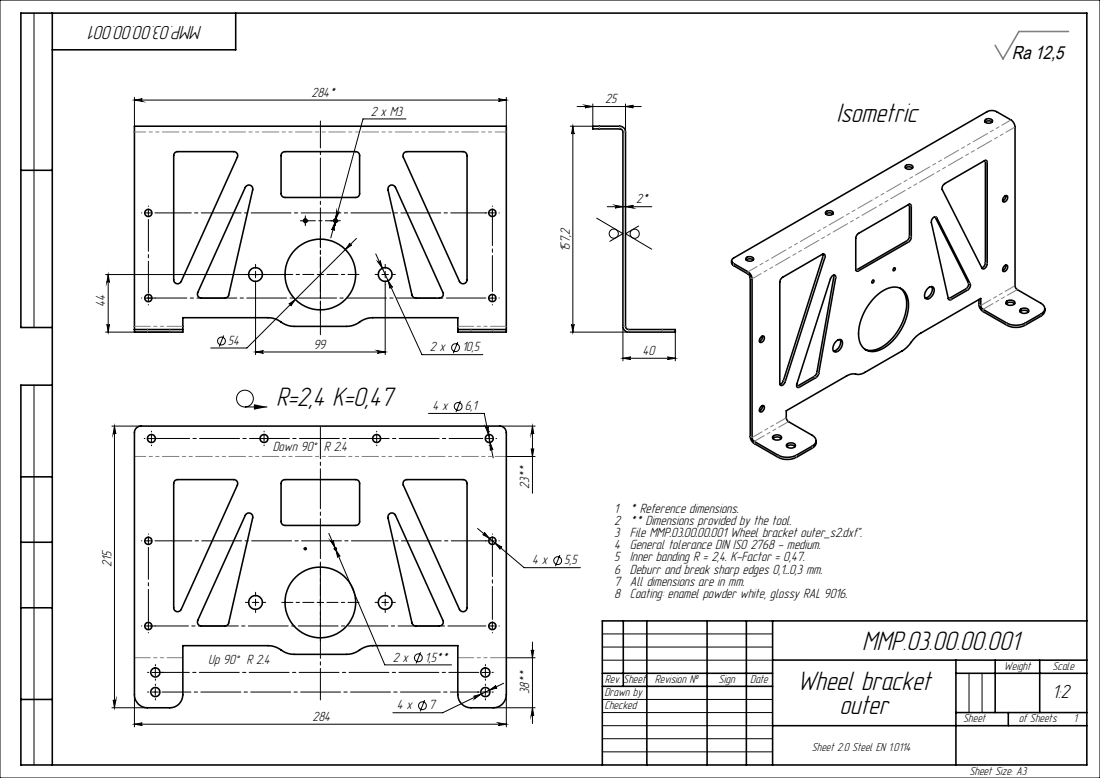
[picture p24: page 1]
Down 90° R 2.4; Sheet Size: А3

1 * Reference dimensions.
2 ** Dimensions provided by the tool.
3 File MMP.03.00.00.001 Wheel bracket outer_s2.dxf".
4 General tolerance DIN ISO 2768 - medium.
5 Inner banding R = 2,4. K-Factor = 0,47.
6 Deburr and break sharp edges 0,1...0,3 mm.
7 All dimensions are in mm.
8 Coating: enamel powder white, glossy RAL 9016.

MMP.03.00.00.001

Wheel bracket | Weight | Scale

Rev. Sheet Revision № | | Sign | Date | | | | 1:2 outer
Drawn by
Checked

Sheet | of Sheets 1

Sheet 2.0 Steel EN 1.0114

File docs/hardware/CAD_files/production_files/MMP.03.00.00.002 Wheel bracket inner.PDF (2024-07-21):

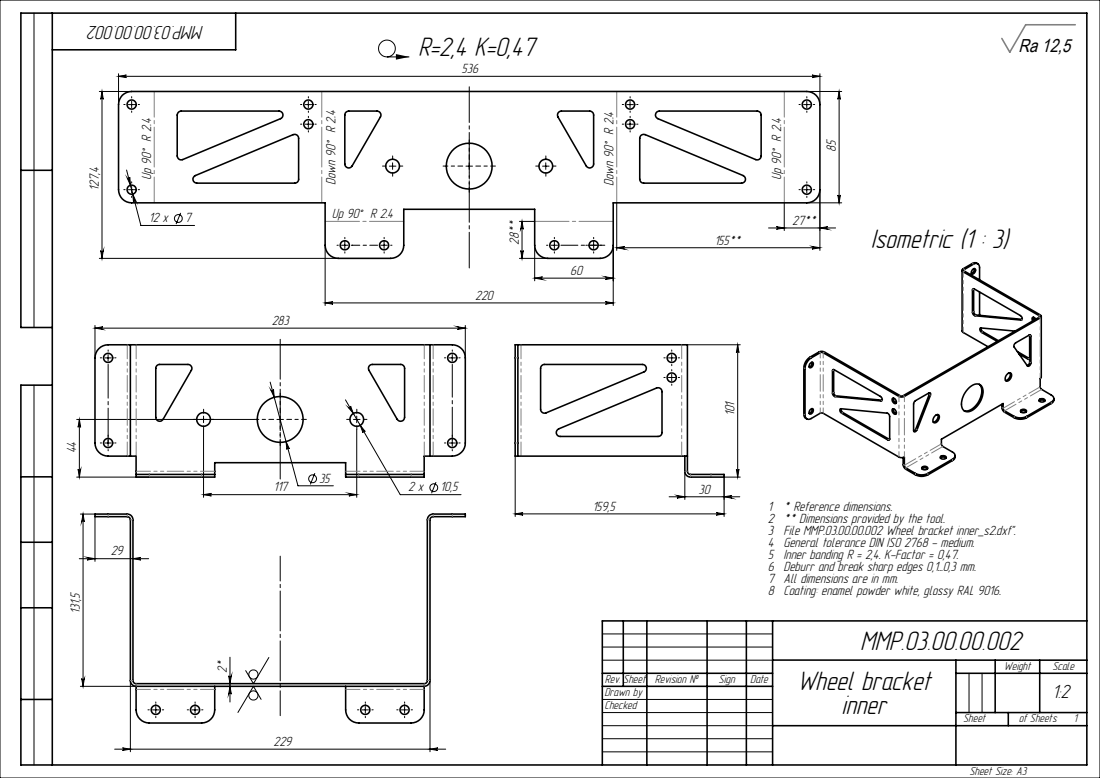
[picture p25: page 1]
Down 90° R 2.4; Isometric (1 : 3); Sheet Size: А3

1 * Reference dimensions.
2 ** Dimensions provided by the tool.
3 File MMP.03.00.00.002 Wheel bracket inner_s2.dxf".
4 General tolerance DIN ISO 2768 - medium.
5 Inner banding R = 2,4. K-Factor = 0,47.
6 Deburr and break sharp edges 0,1...0,3 mm.
7 All dimensions are in mm.
8 Coating: enamel powder white, glossy RAL 9016.

MMP.03.00.00.002

Wheel bracket | Weight | Scale

Rev. Sheet Revision № | | Sign | Date | | | | 1:2 inner
Drawn by
Checked

Sheet | of Sheets 1

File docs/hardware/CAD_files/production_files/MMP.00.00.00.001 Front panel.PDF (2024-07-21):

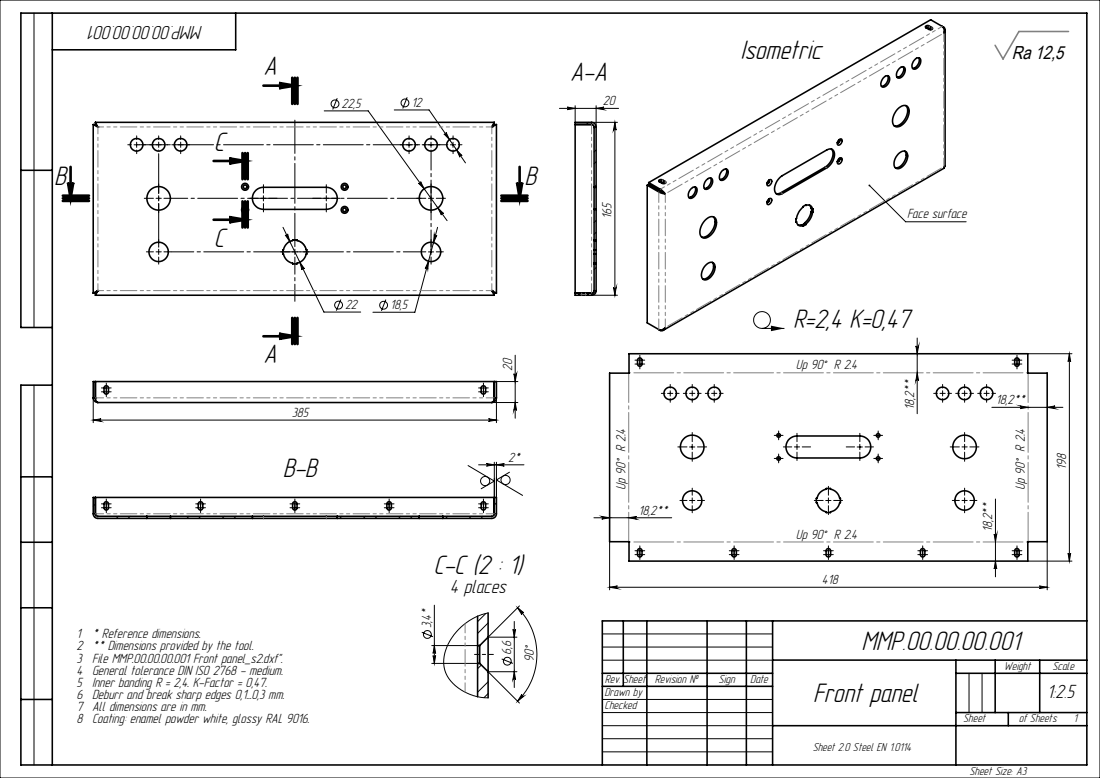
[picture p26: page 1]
Face surface; C-C (2 : 1) 4 places; Sheet Size: А3

MMP.00.00.00.001

1 * Reference dimensions.
2 ** Dimensions provided by the tool.
3 File MMP.00.00.00.001 Front panel_s2.dxf".
4 General tolerance DIN ISO 2768 - medium.
5 Inner banding R = 2,4. K-Factor = 0,47.
6 Deburr and break sharp edges 0,1...0,3 mm.
7 All dimensions are in mm.
8 Coating: enamel powder white, glossy RAL 9016.

Front panel | Weight | Scale

Rev. Sheet Revision № | | Sign | Date | | | | 1:2.5
Drawn by
Checked

Sheet | of Sheets 1

Sheet 2.0 Steel EN 1.0114

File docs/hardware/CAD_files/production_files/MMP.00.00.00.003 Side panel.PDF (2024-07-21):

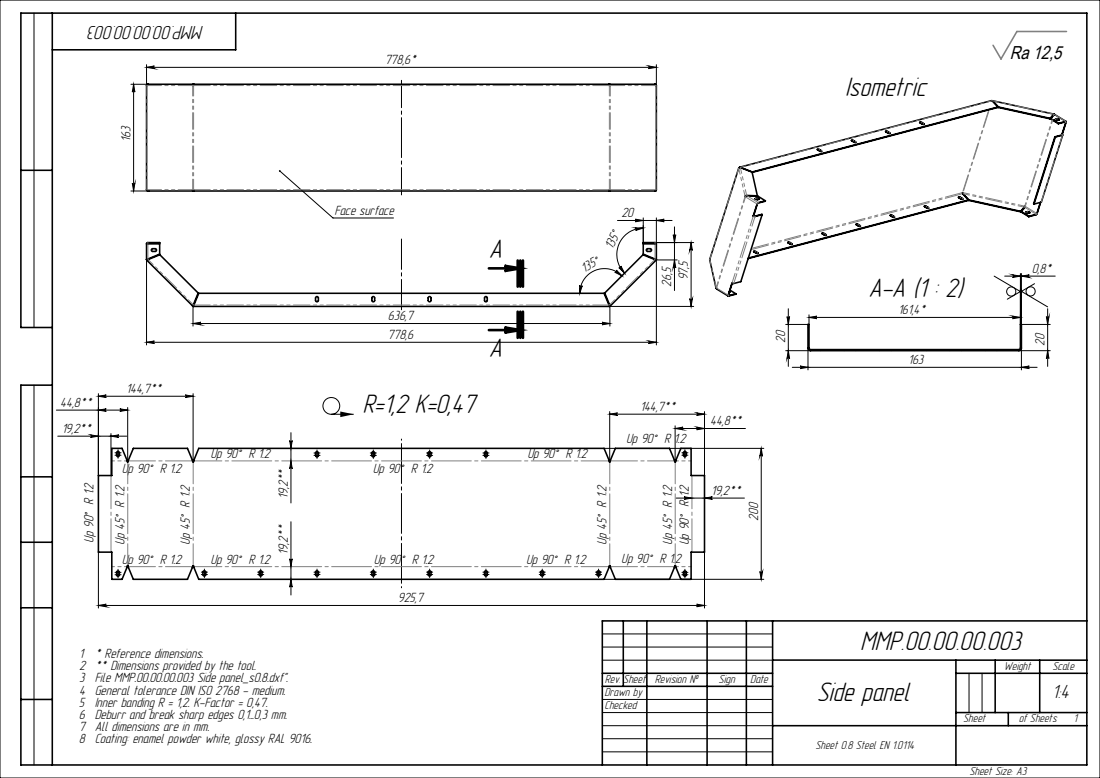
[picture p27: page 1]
Sheet Size: А3

Face surface | 20

MMP.00.00.00.003

1 * Reference dimensions.
2 ** Dimensions provided by the tool.
3 File MMP.00.00.00.003 Side panel_s0.8.dxf".
4 General tolerance DIN ISO 2768 - medium.
5 Inner banding R = 1,2. K-Factor = 0,47.
6 Deburr and break sharp edges 0,1...0,3 mm.
7 All dimensions are in mm.
8 Coating: enamel powder white, glossy RAL 9016.

Side panel | Weight | Scale

Rev. Sheet Revision № | | Sign | Date | | | | 1:4
Drawn by
Checked

Sheet | of Sheets 1

Sheet 0.8 Steel EN 1.0114

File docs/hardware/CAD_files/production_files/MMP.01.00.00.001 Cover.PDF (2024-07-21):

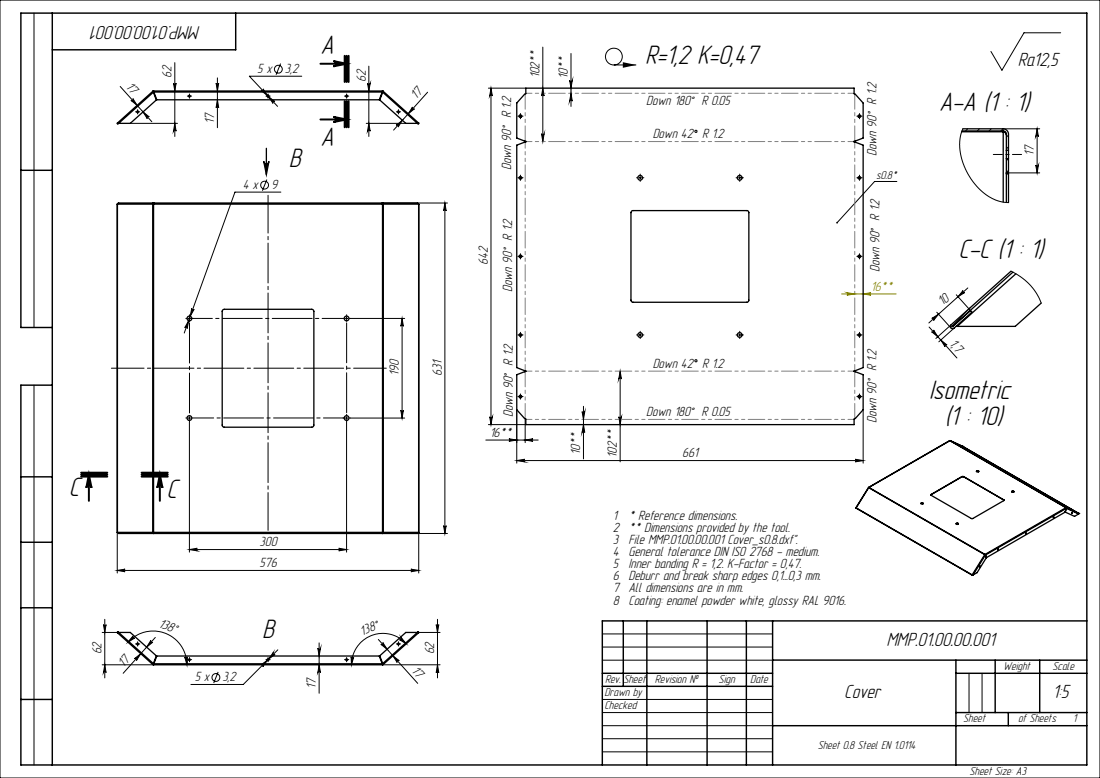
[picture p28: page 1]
Down 42 R 1.2; Down 180° R 0.05; Sheet Size: À3

Down 90° R 1.2 Down 90° R 1.2 Down 90° R 1.2

1 * Reference dimensions.
2 ** Dimensions provided by the tool.
3 File MMP.01.00.00.001 Cover_s0.8.dxf".
4 General tolerance DIN ISO 2768 - medium.
5 Inner banding R = 1,2. K-Factor = 0,47.
6 Deburr and break sharp edges 0,1...0,3 mm.
7 All dimensions are in mm.
8 Coating: enamel powder white, glossy RAL 9016.

MMP.01.00.00.001

Cover | Weight | Scale

Rev. Sheet Revision ¹ | | Sign | Date | | | | 1:5
Drawn by
Checked

Sheet | of Sheets 1

Sheet 0.8 Steel EN 1.0114

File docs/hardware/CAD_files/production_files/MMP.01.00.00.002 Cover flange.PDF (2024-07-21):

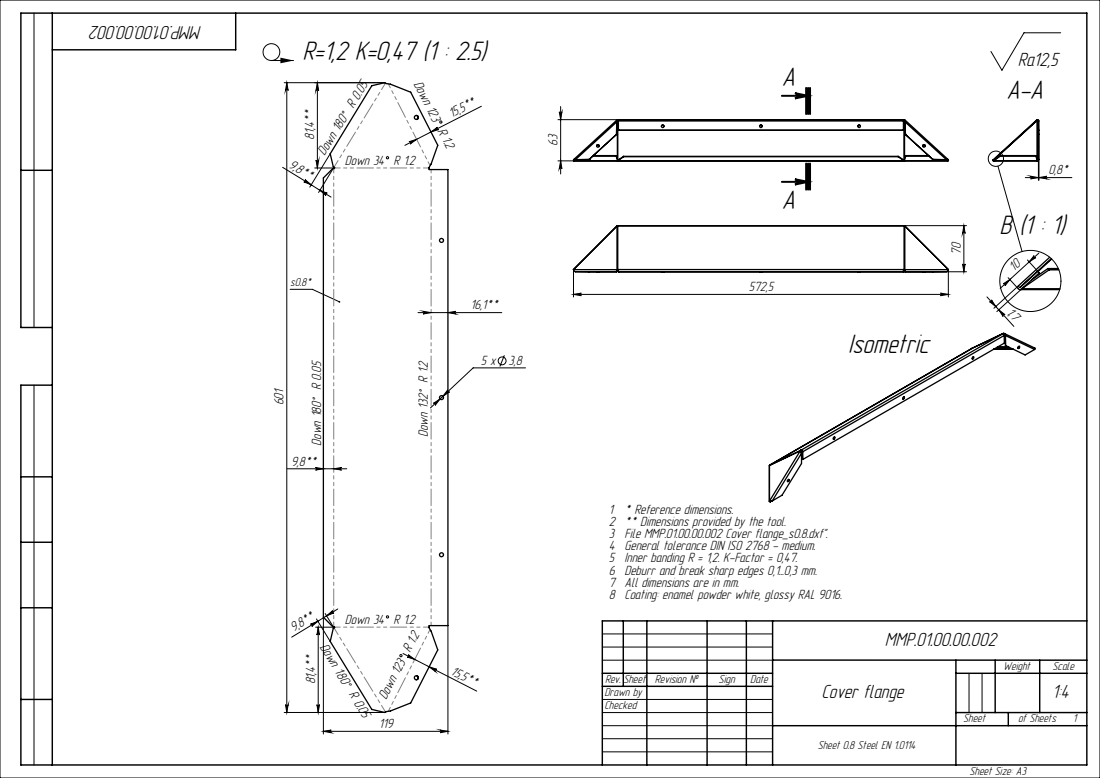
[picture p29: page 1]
Down 123; Down 123 R 1.2; Down 34 R 1.2; Down 132° R 1.2; Down 180° R 0.05 Down 180° R 0.05; Down 180° R 0.05; Sheet Size: À3

1 * Reference dimensions.
2 ** Dimensions provided by the tool.
3 File MMP.01.00.00.002 Cover flange_s0.8.dxf".
4 General tolerance DIN ISO 2768 - medium.
5 Inner banding R = 1,2. K-Factor = 0,47.
6 Deburr and break sharp edges 0,1...0,3 mm.
7 All dimensions are in mm.
8 Coating: enamel powder white, glossy RAL 9016.

MMP.01.00.00.002

Cover flange | Weight | Scale

Rev. Sheet Revision ¹ | | Sign | Date | | | | 1:4
Drawn by
Checked

Sheet | of Sheets 1

Sheet 0.8 Steel EN 1.0114

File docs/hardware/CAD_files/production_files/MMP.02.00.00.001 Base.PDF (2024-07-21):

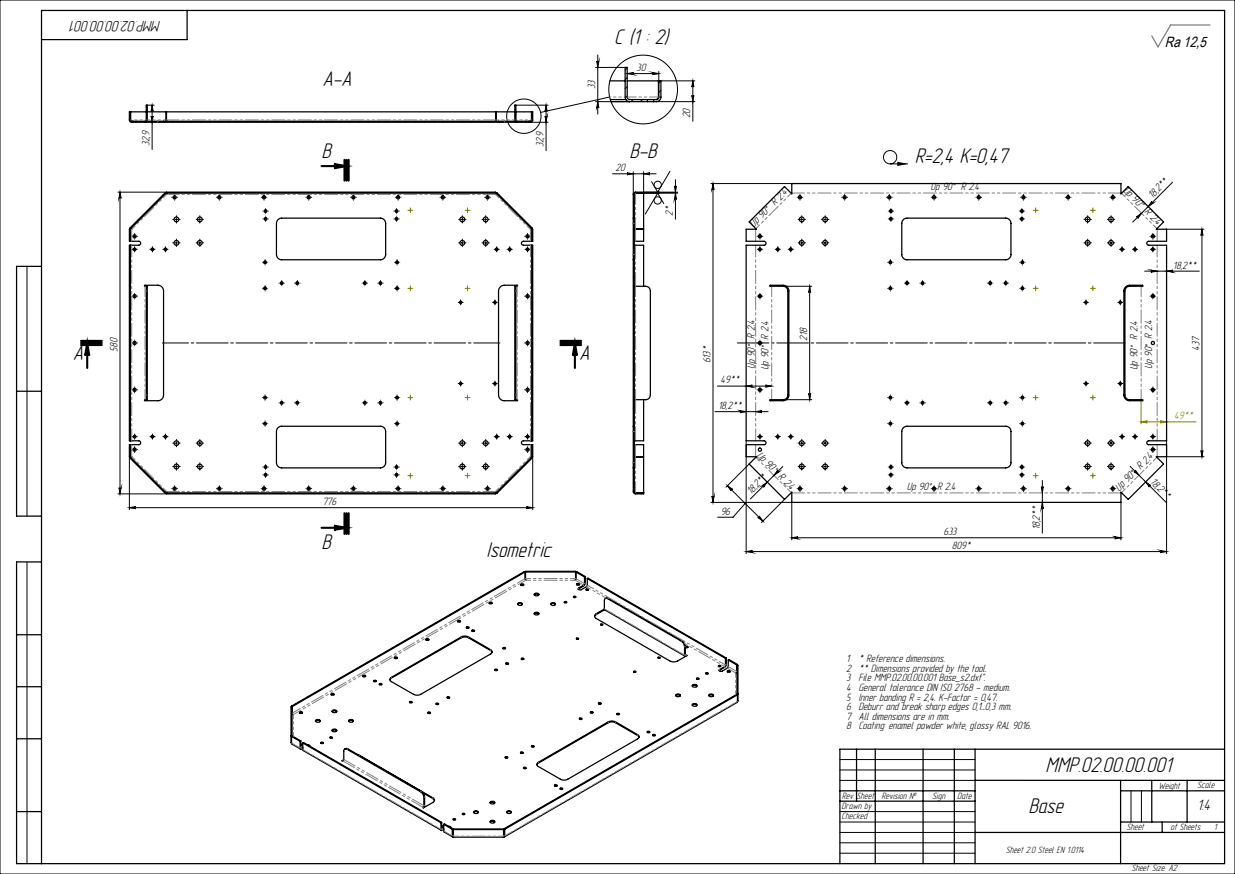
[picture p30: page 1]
Sheet Size: A2

1 * Reference dimensions.
2 ** Dimensions provided by the tool.
3 File MMP.02.00.00.001 Base_s2.dxf".
4 General tolerance DIN ISO 2768 - medium.
5 Inner banding R = 2,4. K-Factor = 0,47.
6 Deburr and break sharp edges 0,1...0,3 mm.
7 All dimensions are in mm.
8 Coating: enamel powder white, glossy RAL 9016.

MMP.02.00.00.001

Base | Weight | Scale

Rev. Sheet Revision № | | Sign | Date | | | | 1:4
Drawn by
Checked

Sheet | of Sheets 1

Sheet 2.0 Steel EN 1.0114

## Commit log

2024-07-21 fixing bug with archives
    [MMP.00.00.00.001 Front panel.SLDDRW, MMP.00.00.00.001 Front panel.SLDPRT, MMP.00.00.00.002 Back panel.SLDDRW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]
2024-07-21 step_full_assembly
    downloading full file without archiving after fixing bug with .gitignore
    [MMP.00.00.00.001 Front panel.DXF, MMP.00.00.00.001 Front panel.STEP, MMP.00.00.00.002 Back panel.DXF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]
2024-08-10 Update README.md
    In the video you can see how and in what sequence to correctly assemble the wheel.
2025-06-14 Delete docs/hardware/BOM/BOM_specs_MMP.xlsx
    mistake with the Z5 motor fixed: changed to Z5 ( the same as in the 3D model)
    [BOM_specs_MMP.xlsx]
2025-06-14 renewed BOM added
    BOM components renewed with Z4 motor model. Mistake with Z5 motor fixed.
    [BOM_specs_MMP.xlsx]
2025-06-14 Update README.md
    Z5 motor changed to correct one - Z4BLD60-24GN-30S/4GN 25K
2026-08-29 docs: cut legacy README to a redirect stub (#23)
    * docs: cut legacy README to a redirect stub
    Part of Phase 1 of the OpenAMRobot documentation audit.
    Claude-Session: https://claude.ai/code/session_01BjdEC9yD6TF3nL6nCygaYS
    * docs: keep the full Stripe support section
    The audit called for deduplicating the support tables. Maintainer decision is to
    keep them on every page that carried them before. All 11 payment URLs and the
    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
2026-08-29 Revert "docs: cut legacy README to a redirect stub (#23)" (#24)
    Restores README.md to its state at 55ff20a, byte for byte.
    openamr is legacy but stays active during the mono-repo to multi-repo
    transition. The original README already describes that new structure and links
    to openamr-platform-hw, -sw, and -fw, so it is restored intact.
    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
2026-08-29 legal: adopt asset-specific licensing and IP notices (#25)
    * legal: standardize original project material under MIT
    * legal: use canonical MIT licence text
    * legal: define MIT scope and third-party exceptions
    * legal: adopt MIT, CC BY 4.0, and CERN-OHL-P-2.0 asset map
    * docs: align licensing summary and contact
    * docs: align licensing summary and contact
    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
